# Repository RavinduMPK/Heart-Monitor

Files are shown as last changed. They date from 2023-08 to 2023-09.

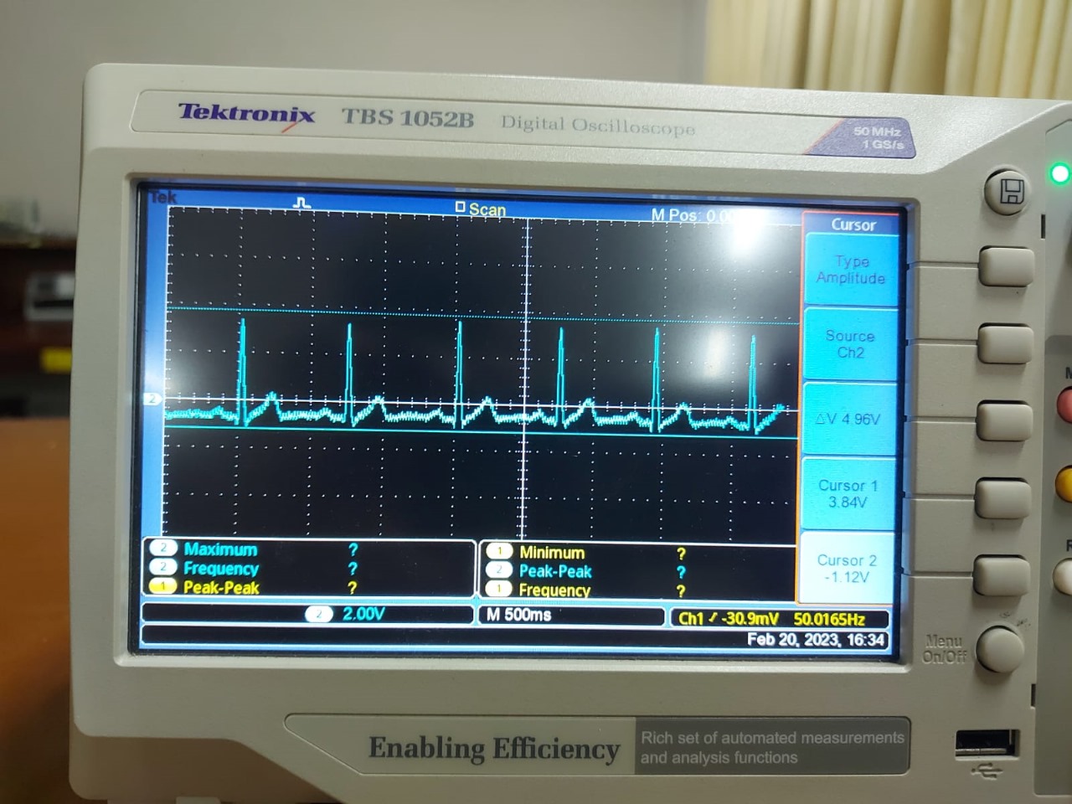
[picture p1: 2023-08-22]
images/Final result.jpg

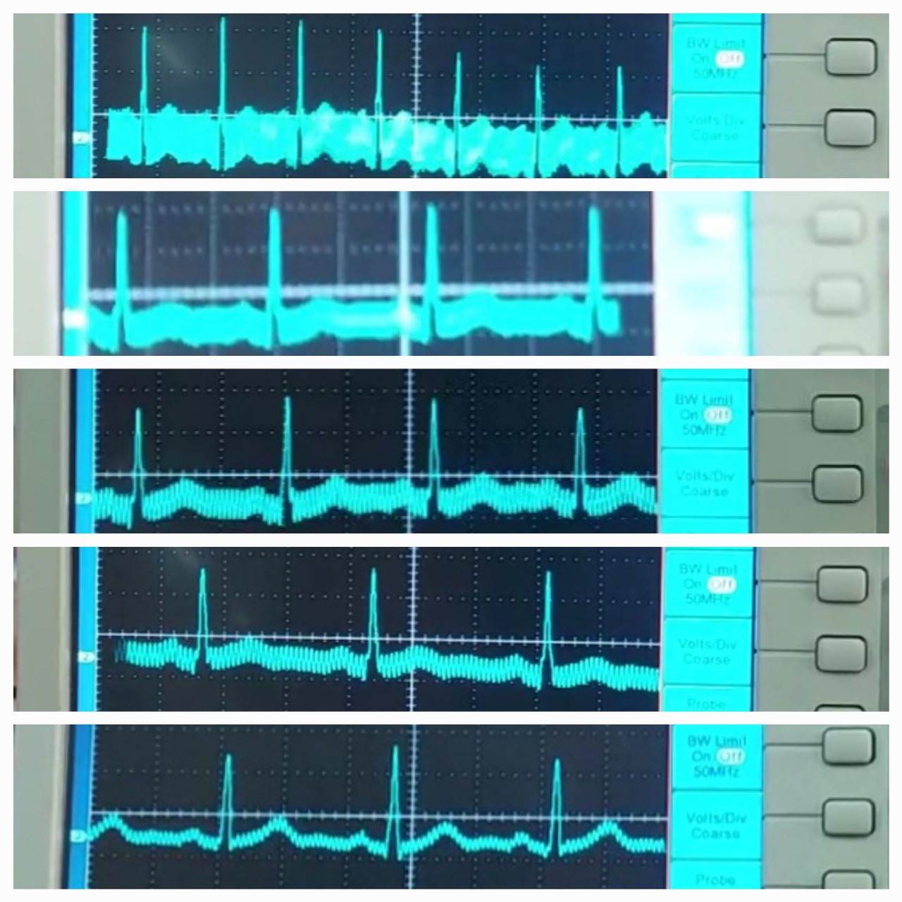
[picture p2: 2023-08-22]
images/Testing process.jpg

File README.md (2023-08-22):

# Heart-Monitor

During our third semester, we successfully designed an Analog Heart Rate Monitor, bringing together the realms of technology and healthcare. The project was also showcased for **EXMO'23** the flagship technological exhibition of the University of Moratuwa as a biomedical application of electronics and technology. 

Our team, consisting of Malith, Ravindu, Umesha, and Dilupa, were able to apply our knowledge of circuit design, PCB design, enclosure design, and software integration to create a device that progresses from sensing the heart rate to amplifying and filtering the signal, culminating in the display of the refined waveform. The main circuitry of the device was developed utilizing analog electronic components, as a learning opportunity of analog electronics as well. 

With the user-friendly interface, we were able to output a patient's ECG waveform in real-time and also tune the signal when necessary. Our project's output results were compared favorably and accurately to a commercial patient monitor. With the wealth of practical and hands-on experience we've acquired, we are poised to continue making impactful contributions to the advancement of healthcare through technology.

Final Product

What you can find here:

- Circuit Design
- Simulation Files
- Schematic Diagrams
- PCB Designs
- Enclosure Designs
- Arduino program file

## The Circuit Design
The ECG circuit mainly consists of 5 blocks. Those are,
- Right Leg Drive Circuit
- Instrumentation Amplifier
- Low Pass Filter
- High Pass Filter
- Notch Filter

When we discuss our design approach to the circuit;

### The Right Leg Drive Circuit
The right leg drive circuit (DRL) is used to reduce common-mode interference. Common-mode interference is unwanted electrical noise that is picked up by the ECG electrodes and amplified along with the ECG signal. This noise can obscure the ECG signal and make it difficult to interpret.

The DRL circuit works by injecting a known voltage into the right-leg electrode. This voltage is equal to the common-mode voltage that is being picked up by the other electrodes. The ECG amplifier then subtracts this known voltage from the signal from the other electrodes, effectively canceling out the common-mode noise.

The DRL circuit is typically used in conjunction with other methods of noise reduction, such as filtering and shielding. The choice of which methods to use depends on the specific application.

Leg Drive

### Instrumentation Amplifier
An instrumentation amplifier is a critical component in our ECG circuit design. Its primary purpose is to amplify sensitive electrical signals originating from the body while minimizing distortion. This is crucial for accurate ECG signal acquisition since the electrical potentials generated by the heart are extremely low in amplitude.

The instrumentation amplifier consists of multiple operational amplifiers arranged in a specific configuration to achieve high common-mode rejection ratio (CMRR), which helps in removing unwanted noise that is picked up by the electrodes. By effectively amplifying the difference between two input signals while rejecting common-mode signals, the instrumentation amplifier improves the signal-to-noise ratio of the ECG measurement.

In addition to amplifying the ECG signal, the instrumentation amplifier also provides a means to adjust the gain as needed. This enables customization of the signal's amplitude for optimal visualization on the display.

Instrumentation Amplifier

### Low Pass Filter
We implemented a 5th order Bessel-Thompson low pass filter in our circuit. This filter is designed to attenuate high-frequency noise and unwanted components beyond a certain cutoff frequency while preserving the integrity of the ECG signal. The Bessel filter is chosen for its minimal group delay, which helps maintain the shape and timing of the ECG waveform.

The Bessel-Thompson filter comprises a series of cascaded first-order and second-order active filter stages. These stages collectively contribute to the filter's response, ensuring that frequencies beyond the cutoff are effectively attenuated while minimizing distortion and phase shift. By carefully selecting the filter's components and structure, we ensure that the amplified ECG signal is clean and devoid of high-frequency noise.

Low Pass filter

### High Pass Filter
Our ECG circuit incorporates a 3rd order active inverting Butterworth high-pass filter. This filter serves multiple purposes, including removing the DC offset that may develop between the electrodes and further amplifying the signal.

The high-pass filter's design focuses on attenuating low-frequency components, which typically include DC offset and slow baseline drift. The filter's configuration involves a cascade of a second-order active non-inverting stage followed by a first-order active inverting stage. The combined effect of these stages results in eliminating DC offset while providing additional signal amplification.

A variable resistor is integrated into the high-pass filter, allowing us to adjust the gain of the first-order filter stage according to the requirements of the specific ECG measurement.

High pass filter

### Notch Filter
To eliminate the interference caused by the 50 Hz power line frequency, we integrated a Twin-T type notch filter into our ECG circuit.

The Twin-T notch filter is known for its ability to provide a deep notch at a specific frequency, making it effective at eliminating power line interference. In our case, the notch frequency is set to 50 Hz to target the power line frequency. The filter's quality is determined by the Q factor, which influences the sharpness of the roll-off at the notch frequency.

To accommodate variations in the interference and notch frequency, we included a variable resistor that allows us to adjust the Q factor and achieve optimal filtering. This ensures that the ECG waveform remains free from the influence of power line noise, contributing to accurate and reliable heart rate measurements.

With these components and configurations, our analog heart rate monitor circuit is capable of capturing, amplifying, and filtering the ECG signal to produce a clean and accurate representation of the heart's electrical activity. The combination of the right leg drive circuit, instrumentation amplifier, low pass filter, high pass filter, and notch filter results in a robust ECG measurement system suitable for biomedical applications.

Notch Filter

## Simulation 
We used LTspice software to simulate and verify our circuit.
Simulation

## The Enclosure Design
The enclosure was designed by Solidworks software. It contains a removable top lid, a removable front, and the main body. The removability was integrated to fix and replace components. Holes surrounding the box are integrated to ensure that the heat flow to the outside of the box due to the power components inside. A fan is also connected inside to help with this. The front contains the display and also the knobs for tuning the filters. The switch on top switches off the device, and can be used for temporary situations. And the switch at the back, switches off the transformer as well, saving
the power loss that happens at the transformer. The enclosure also contains holes containing the adapters to connect the power cable and also to
connect the 3.5mm jack.

Enclosure main
Enclosure full
Enclosure front

## PCB Design
The heart rate monitor's PCB design involved several key considerations that contributed to the final product's performance and reliability. One of the pivotal decisions was the configuration of a 4-layer PCB. This choice allowed us to take advantage of its multilayer structure for improved signal integrity, reduced interference, and effective heat dissipation.

The arrangement of the layer stack was meticulously planned to optimize the PCB's performance. By thoughtfully allocating power and ground planes and strategically positioning signal traces, we aimed to create a layout that minimized noise and interference while providing stable voltage references for our sensitive analog components.

In the process of routing traces, special attention was given to the layout's integrity. We took great care to minimize issues such as cross-talk, impedance mismatches, and electromagnetic interference.

PCB layers

The placement of components on the PCB played a vital role in achieving signal fidelity and effective thermal management. Components were arranged to minimize signal distortion and ensure efficient heat dissipation. By considering the interaction between components, we aimed to create a layout that enhanced the overall functionality and reliability of the heart rate monitor.

PCB

Upon finalizing the PCB design, we collaborated with JLC PCB, a reputable PCB manufacturer, for production. Their expertise and advanced manufacturing processes ensured the accurate reproduction of our design.

## Testing and Final Results
Throughout the development of our heart rate monitor project, rigorous testing played a pivotal role in ensuring the accuracy and reliability of our device. Initially, we implemented the circuit on breadboards, meticulously connecting components and validating the functionality of each stage. This iterative testing approach allowed us to address any issues early in the design process and refine our circuitry.

Bread board implementation

To observe the ECG waveform and monitor signal behavior, we utilized an oscilloscope. This powerful tool enabled us to visualize the signal characteristics, detect any anomalies, and fine-tune our circuit parameters for optimal performance.

Testing process

Recognizing the dynamic nature of power line interference, we introduced variable resistors into the notch filter circuit. This innovation provided us with the flexibility to adjust the notch filter frequency as needed. By adapting to variations in interference over time, we could consistently attain a clean and accurate ECG waveform.

After iterative adjustments and thorough testing, we achieved our goal: a heart rate monitor that delivered more accurate and reliable ECG waveforms. The collective efforts of our team, from circuit design and simulation to PCB layout and meticulous testing, culminated in a final product that accurately captures and displays the heart's electrical activity. This accomplishment underscored the success of our project and its potential to make meaningful contributions to healthcare through technology.

Final result

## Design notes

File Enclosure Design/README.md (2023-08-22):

##  Enclosure Design using Solidworks

The enclosure of our heart rate monitor project was meticulously crafted using Solidworks, a powerful 3D modeling software. This phase of the project was essential to provide a robust and functional housing for our circuitry and components.

In our enclosure design, we took a comprehensive approach to ensure that all components were accommodated optimally. Spaces were carefully planned and designed to house the three PCBs that constituted the heart rate monitor's intricate circuitry. By providing dedicated mounting areas for each PCB, we enhanced the structural integrity and organized layout of the device.

The transformer, a pivotal component in our power supply circuit, also found its place within the enclosure. We allocated a specific location for the transformer, ensuring it was securely mounted while considering ventilation for heat dissipation.

To address thermal management, a cooling fan was incorporated into the design. The enclosure was thoughtfully crafted to accommodate the cooling fan, ensuring proper airflow to prevent overheating and maintain consistent performance.

Display visibility and user interaction were prime considerations in our design. We created an optimized space to mount the display, ensuring it was easily viewable and integrated seamlessly with the enclosure. User-adjustable components, such as potentiometers for tuning filters, were also given careful attention to make sure they were comfortably accessible without compromising the overall aesthetics and functionality.

Furthermore, we meticulously designed holes for the input and output interfaces. This included crafting holes to mount the 3.5mm audio jack for signal input, as well as apertures for power input and cable connections. These precise apertures ensured seamless connectivity while maintaining the enclosure's clean and professional appearance.

The culmination of our enclosure design was achieved through local 3D printing. By translating our Solidworks design into a physical enclosure, we created a protective casing that encapsulated our entire heart rate monitor project. This enclosure not only served as a shield against external elements but also contributed to the aesthetic appeal of the final device.

In essence, our Solidworks-based enclosure design was a testament to our commitment to detail and functionality. By thoughtfully considering the arrangement of components, thermal management, user interaction, and structural integrity, we created a housing that complemented the sophistication of our internal circuitry. The successful local 3D printing of the enclosure brought our design to life, underscoring the importance of an integrated and holistic approach to device development.

Enclosure

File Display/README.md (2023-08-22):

## Display
The final stage of our heart rate monitor project involved translating the analog ECG signal into a digital format and presenting it on a visual display. To accomplish this, we employed an ATmega328p microcontroller. This microcontroller served as the bridge between the analog world of our ECG signal and the digital realm of data processing.

Given the ATmega328p's input range limitation of 0V to 5V, a re-scaling of our ECG output was necessary. To achieve this, we designed a dedicated circuit and PCB that accurately converted the amplified ECG signal to fit within the ATmega328p's operating range.
Offset Circuit

Once the hardware was in place, we proceeded to code the ATmega328p microcontroller. The code was responsible for interfacing with the analog-to-digital converter (ADC) of the microcontroller, reading the re-scaled ECG signal, and then driving the visual display. Through careful coding and calibration, we ensured that the digital representation of the ECG waveform accurately mirrored the heart's electrical activity.
Display Circuit

In essence, this final phase of the project brought together hardware design, analog-to-digital conversion, microcontroller programming, and display output. The result was a user-friendly display that showcased the heart rate monitor's output in a clear and informative manner, making it accessible and valuable for medical professionals and patients alike.

Display PCB

Display 3D

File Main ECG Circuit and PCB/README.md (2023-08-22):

Here I have added Altium Design Files (Schematics, PCB files) and also zipped Altium Project.

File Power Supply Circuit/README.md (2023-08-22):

## Power Supply Circuit

The power supply circuit in our heart rate monitor project was a critical component that provided the necessary electrical energy for the device to function reliably. Here are the key aspects of our power supply design:

To power our device, we utilized a domestic AC power supply rated at 230V/50Hz. Given the different voltage and nature of the AC supply compared to our device's requirements, we needed to go through several steps of transformation and regulation.

We began by stepping down the voltage from 230V AC to a safer and usable level. To achieve this, we incorporated a 230V to 15V step-down transformer. This initial transformation ensured that the voltage was within an appropriate range for further processing.

The next step was to obtain a stable DC output for the heart rate monitor's internal circuitry. For this purpose, we designed a power supply PCB that included a rectifier bridge and voltage regulators. The rectifier bridge efficiently converted the AC voltage to a pulsating DC voltage, and then we employed L7812 and L7912 voltage regulators to generate +12V and -12V DC outputs, respectively.

As our circuit incorporated operational amplifiers (opamps), it was necessary to have both positive and negative supply voltages. Therefore, the power supply design incorporated both +12V and -12V lines to accommodate the requirements of the opamps.

To ensure smooth and stable DC outputs, we integrated smoothing circuits that reduced the residual ripple in the rectified DC signal. This smoothed DC output was vital to provide a clean and reliable power source for the heart rate monitor's sensitive analog circuitry.

Power Supply Circuit

Power Supply PCB

Power Supply PCB 3D

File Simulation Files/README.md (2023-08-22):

## Circuit Simulation

Simulation played a crucial role in ensuring the accuracy and reliability of our heart rate monitor project. To achieve this, we turned to LTspice, a powerful simulation tool, to thoroughly design and validate our circuitry before physical implementation.

We embarked on our simulation process by breaking down our circuit into its sub-circuits, mirroring the actual components and connections in LTspice's virtual environment. This allowed us to accurately model the behavior of each individual component, ensuring that our design was free from inherent errors and inconsistencies.

By simulating our sub-circuits within LTspice, we gained valuable insights into how they interacted and responded to varying inputs. This simulation stage allowed us to fine-tune parameters and values to optimize the performance of each circuit block.

One of the key advantages of LTspice was its ability to provide a comprehensive analysis of the circuit's behavior. We could observe waveforms, plot graphs, and analyze parameters such as gain, frequency response, and signal distortion. This level of detail enabled us to detect potential issues and make informed design decisions early in the process.

Furthermore, LTspice aided us in pinpointing potential areas of concern, such as noise susceptibility and unwanted distortion. This proactive approach empowered us to address such issues in the simulation stage, leading to a more robust and reliable final circuit design.

The LTspice simulations also helped us validate our circuit's functionality under various scenarios, such as different heart rate patterns and noise interference. This extensive testing gave us confidence that our heart rate monitor would perform accurately in real-world situations.

Simulation

*_And also we used ECG waveform sample signal to verify our circuit_*

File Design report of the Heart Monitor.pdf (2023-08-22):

## Department of Electronic & Telecommunication Engineering Faculty of Engineering University of Moratuwa

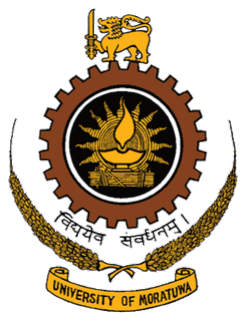
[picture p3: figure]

# Heart Monitor

by CardioTech

Bandara D.M.D.V. | Jayalath K.A.D.M.P.
Undergraduate (Biomedical engineering) | Undergraduate (Biomedical engineering)
Department Electronic and Telecommunications | Department Electronic and Telecommunications
Faculty of Engineering | Faculty of Engineering
University of Moratuwa | University of Moratuwa
Pushpakumara H.M.R.M. | Tilakarathna U.A.
Undergraduate (Biomedical engineering) | Undergraduate (Biomedical engineering)
Department Electronic and Telecommunications | Department Electronic and Telecommunications
Faculty of Engineering | Faculty of Engineering
University of Moratuwa | University of Moratuwa

February 28, 2023(ongoing)

## Contents

1 Introduction | 1
2 Design Specifications | 1
3 Functionality Description | 2
4 Design Parameters | 4
5 PCB Design and Soldering | 5
6 Enclosure Design | 5
7 Simulation and Testing | 5
8 Results | 5
9 Task allocation | 6
References | 6
Appendix I: Schematics, PCB’s, Enclosure | 7
Appendix II: Simulation and Testing | 9
Appendix III: Display Code | 12

I

## Abstract

Our project is a heart monitor that outputs and displays the ECG waveform. The challenge is to amplify the small ECG voltage signal of range 0.1mV - 10 mV which gets largely affected by noise. To achieve this a leg drive circuit, an instrumentation amplifier, a high pass filter, a low pass filter and a notch filter were used. The bandwidth considered was 160 Hz. To achieve this, only analog electronic components were used. Digital electronic components were used only in the digital circuit. Simulation testing, breadboard testing, and PCB testing was done to test the functionality of the circuit. A 3D enclosure was designed and built to suit the device.

## 1 Introduction

An electrocardiogram (ECG) is a simple test that can be used to check the heart’s rhythm and electrical activity through sensors attached to the skin, which detects electrical signals generated by the heart each time it beats. The voltage between right arm and left arm is amplified while having a feedback mechanism through the right leg. These voltages of right arm, left arm and right leg are taken from ECG leads (Figure 1). The amplitude of the voltage signal has a range of 0.1 mV-10 mV; while its frequency falls into 0.01 Hz-250 Hz. Amplifying this signal becomes a challenge due to the small amplitude of the ECG raw signals and their ease of corruption due to noise and disturbances such as power line interference, electrostatic potentials, RFI, electrode contact noise, stray capacitance, nearby electronic devices and also bio signal artifacts introduced into an ECG by subject movement, respiration and muscle tension. In certain situations, noise can override the ECG waves and make the amplified signal useless.

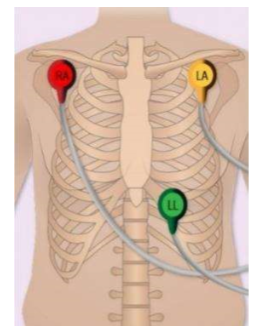
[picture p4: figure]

Figure 1: 3 Lead ECG placement (https://www.conectmed.com/3-lead-ecg-and-placement.html)

Our project is an ECG device, which amplifies and displays the above mentioned voltage waveform. We only used analog electronic equipment except for the display unit. In this report we have explained how we achieved this. For the ECG waveform generation, we have used below mentioned circuits to achieve the final output.

1. Right Leg Drive Circuit.
2. Instrumentation Amplifier.
3. 3

rd Order active Butterworth high pass filter.

4. 5

th Order active Bessel Thompson low pass filter.

5. Notch Filter.

And two separate circuits, with a PCB for each was used for power supply and display screen. In each filter circuit, we have used variable resistors to adjust the gains, adjust and reduce noise and disturbances depending on the location, and unstable power supplies. The total approximate gain achieved through adjustments in the circuit is 1000.

## 2 Design Specifications

### 2.1 Filter Specifications

The ECG falls onto the frequency range of 0.01 Hz
- 250 Hz. The American Heart Association (AHA) recommends a minimum bandwidth of 150 Hz for children between the ages of 12 to 16 years; and a minimum bandwidth of 125 Hz for adults. To filter out the signal to this range from the noise and other disturbances, three filters are used. The high pass filter cut off frequency we used was 0.05 Hz and the low pass filter cut off frequency was 160 Hz. Conductive gel between leads and the body also supports minimizing noise.
The other main issue is the power line interference. To avoid this a notch filter of 50 Hz is used in the circuit.
The overall gain of the ECG waveform should be above 1000 as per the standards. Therefore, the filter gain is made such that this goal is achieved. Variable resistors are used in the filters to increase and decrease the gain as necessary.

### 2.1.1 Op amp Selection

To reduce the high noise added to the small raw ECG signal, an op amp with high CMRR is used in the instrumentation amplifier. Generally, the

CMRR should at least be above 100dB, therefore, we used the LM4562 opamp which has a typical CMRR of 120dB.

### 2.2 Sampling Rate

The sampling ADC sampling rate chosen was 15,000 samples per second. This is the maximum sampling rate of the ADC of the Atmega328pU chip.

## 3 Functionality Description

### 3.1 ECG Circuit

Block Diagram

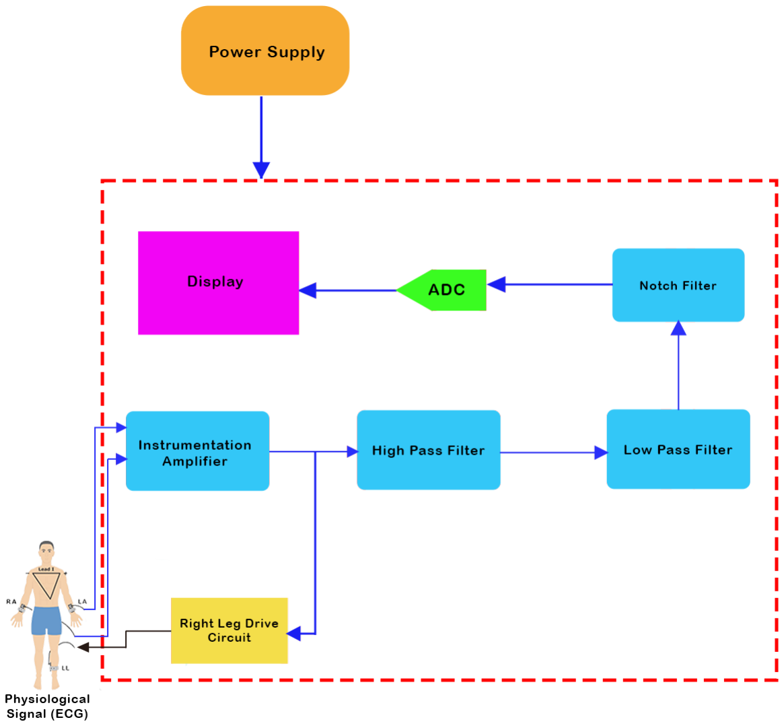
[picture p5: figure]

### 3.1.1 Right Leg Drive Circuit

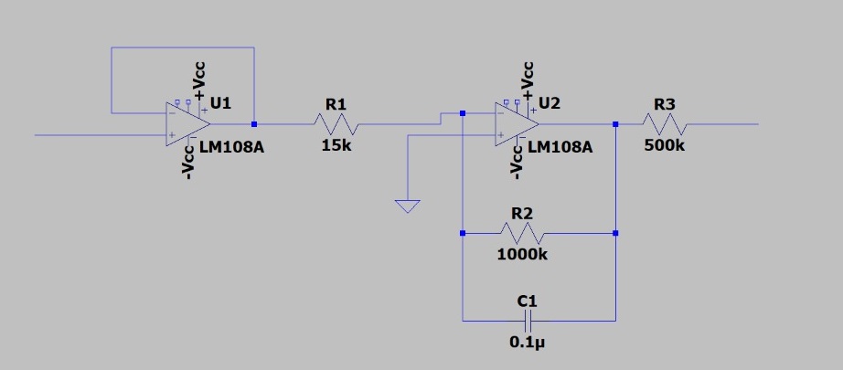
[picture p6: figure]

Figure 2: Right Leg Drive

A right leg drive circuit is used to cancel the common-mode signal between the left and right arm electrodes by inverting, amplifying, and then feeding the signal back to the body through the right leg electrode.The high value resistors used in this circuit also ensures that the patient connected does not get in contact with a bigger current.

### 3.1.2 Instrumentation amplifier

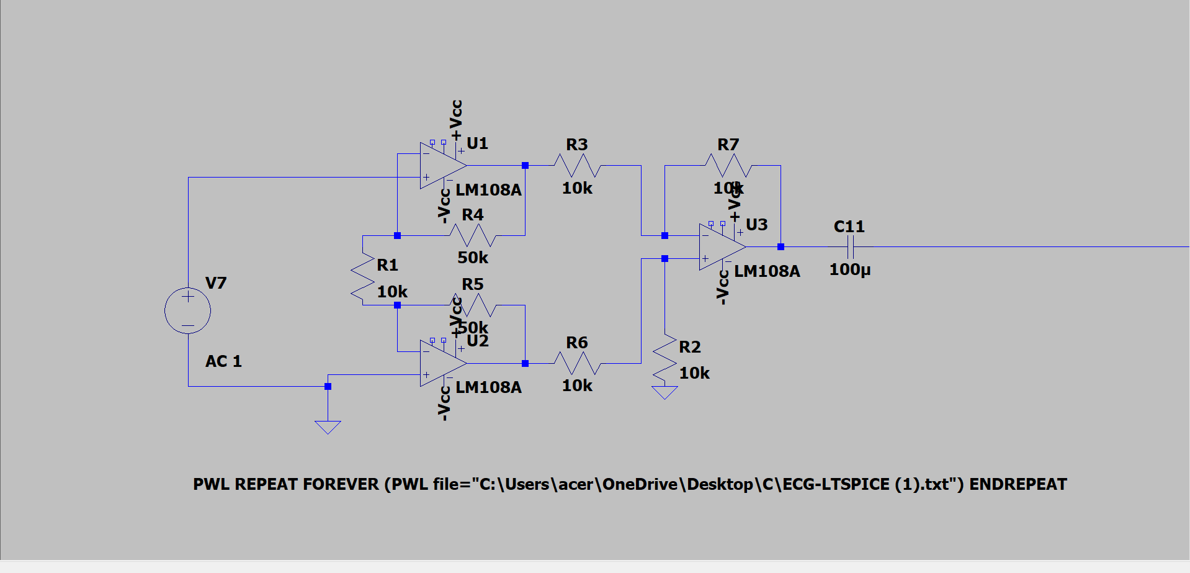
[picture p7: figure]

Figure 3: Instrumentation amplifier

This circuit is used to amplify the signal, while removing the common noise of the voltages from ECG leads. The three inputs are converted to the single output through this circuit. The gain of our circuit in the instrumentation amplifier is kept in the range 20-50. We have used a variable resistor at R1(Refer figure 1) to adjust the gain as necessary.

### 3.1.3 High Pass Filter

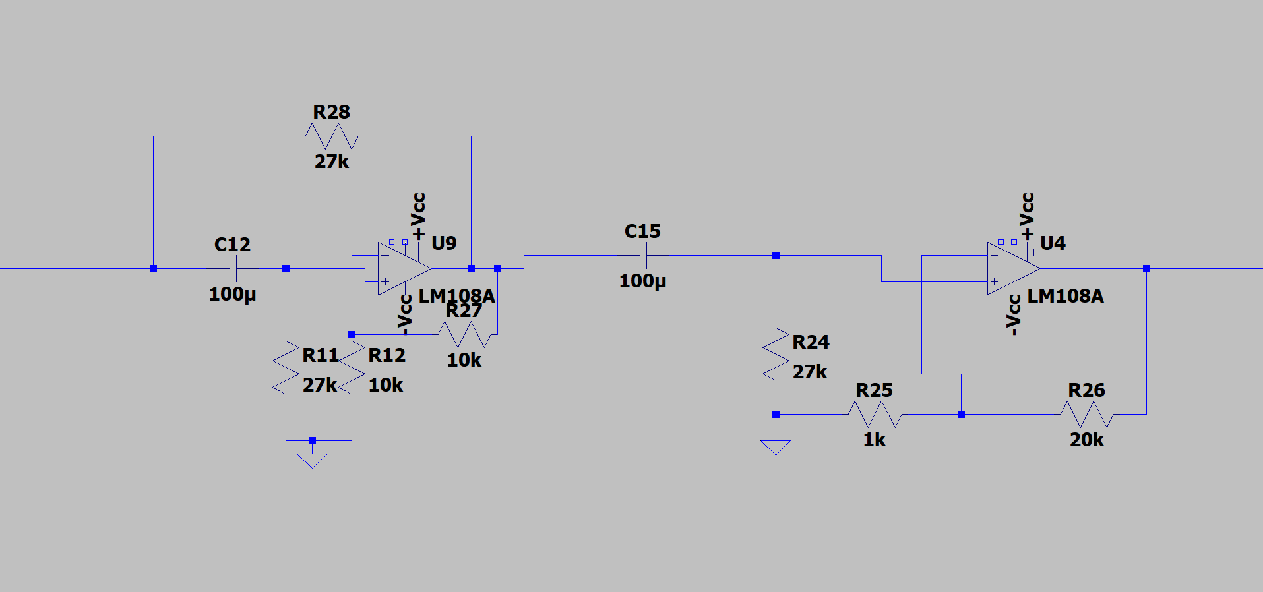
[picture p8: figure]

Figure 4: High Pass Filter

Here we have used 3rd order active inverting Butterworth filter. This consists of a cascaded second order active non inverting filter and a first order active inverting filter. This circuit eliminates the DC offset developed between the electrodes, and also amplifies the signal further. The gain of the second order filter is 2, and the minimum gain of the first order filter connected is 20, making the minimum overall gain of the high pass filter 20 × 2 = 40. The gain of the first order filter can be further increased when required through the variable resistor connected.

### 3.1.4 Low Pass Filter

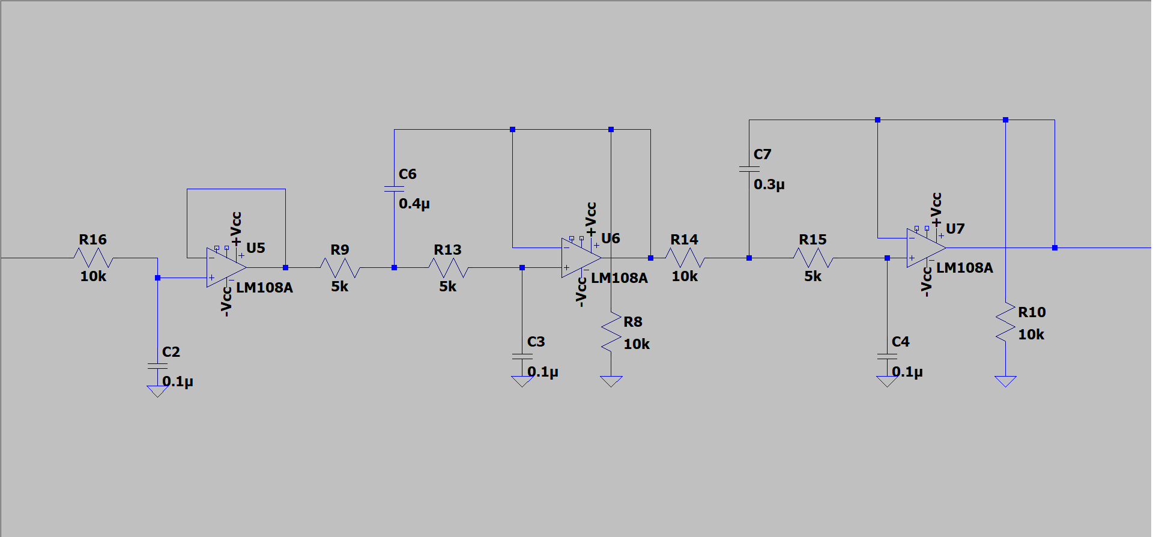
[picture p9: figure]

Figure 5: Low Pass Filter

Here, we used a 5th order Bessel Thompson non inverting filter. Compared to the Butterworth filter, since the group delay and the signal distortion caused is absent, we chose this filter. This consists of a series cascaded first order active filter, and two second order active filters. The gains of each are unity, causing the overall gain of the low pass filter a unity. No adjustments to the gain are made, and therefore, we didn’t use a variable resistor here.

### 3.1.5 Notch Filter

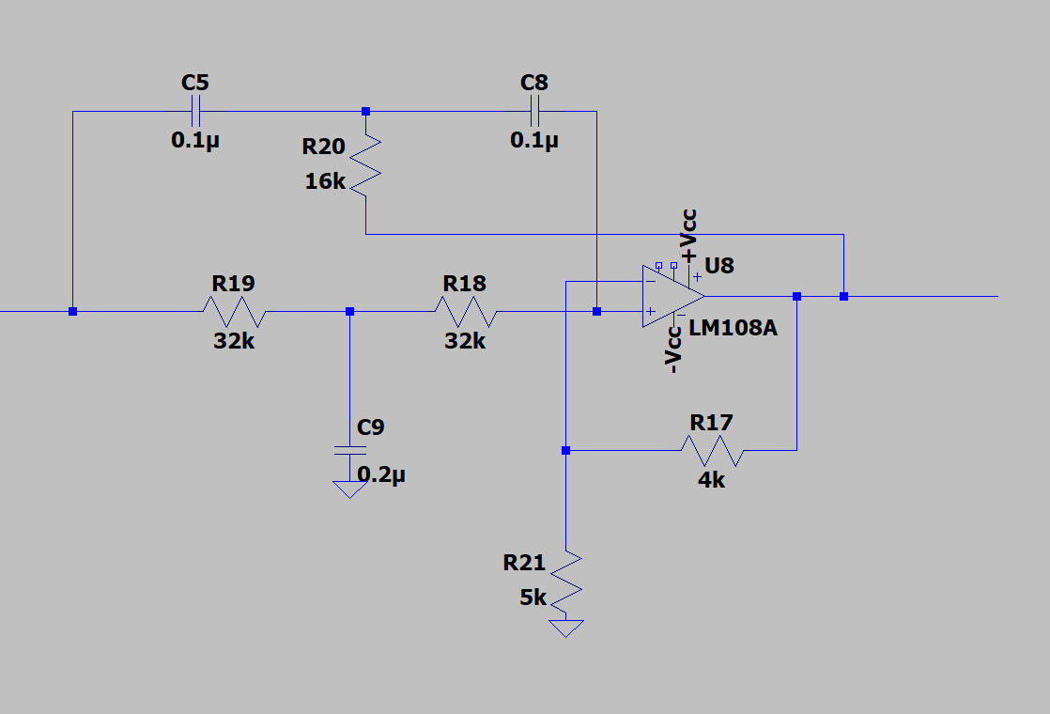
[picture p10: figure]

Figure 6: Notch Filter

Here we have used a Twin-T type notch filter. This is used to eliminate the power line interference. Therefore the notch filter frequency is 50 Hz. This requires a small transition bandwidth or high Q factor to achieve the steeper roll-off. A Twin-T notch filter is one of the few RC networks capable of providing an infinite deep notch at a particular frequency. Therefore, we used this particular filter. The Q factor, or else known as the quality factor determines the quality of the filter. To adjust this as necessary, a variable resistor is used as. The notch frequency depends on three resistor values. To adjust that when necessary, three tuners are used.

### 3.2 Display Circuit

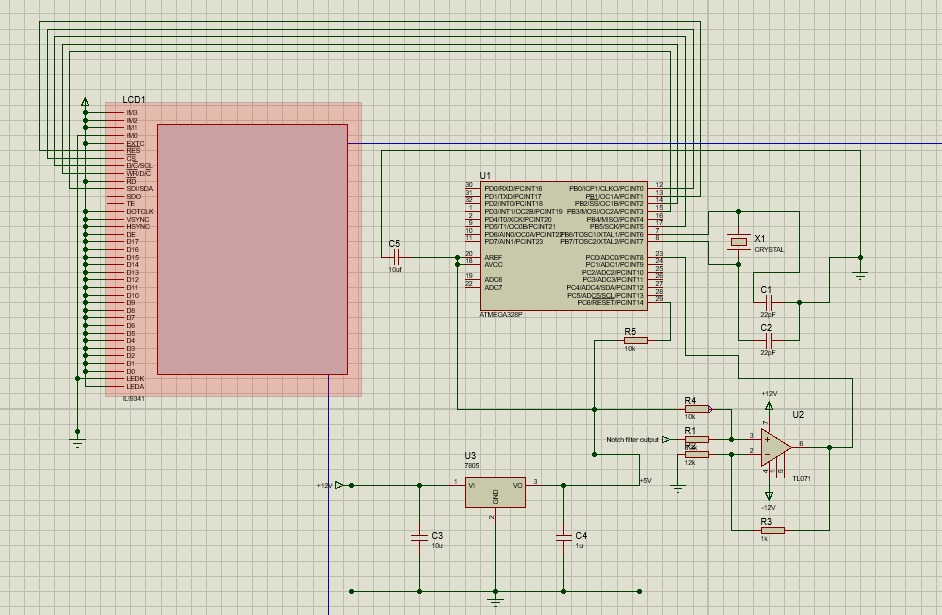
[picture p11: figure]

Figure 7: Display

The output from the notch filter is directed through an Atmega328pU chip to a display to plot the ECG waveform and display it in real time. In the circuit, we bring down the 12V supply to 5V (Using a L7805 regulator) to power the Atmega chip and the display. Another 2-pin outlet is also designed in here to power the fan. The code is provided in the appendix (cite)

### 3.3 Power Supply Circuit

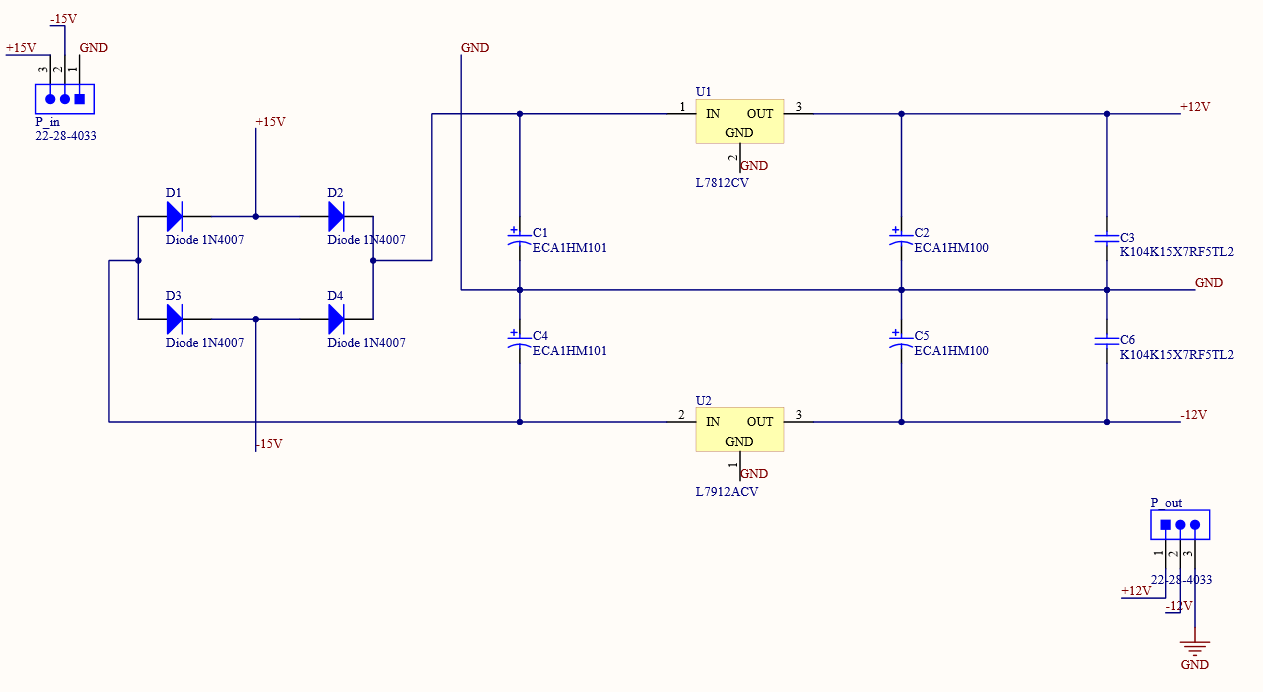
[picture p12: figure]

Figure 8: Power Supply

As we need a power supply of +12V, 0V and -12V s for the functionality of the op amps, we built a separate circuit to provide the required voltages. Here, the AC voltage of household of 230 V, is sent through a center tap transformer that outputs two AC signals of 30 V peak to peak value. These two signals are sent through rectifier diode circuit to make the signals DC, and then through 7812 to regulate the DC voltage to +12 V and then through 7912 to regulate -12 V.

## 4 Design Parameters

- Gain resistor value of instrumentation amplifier:

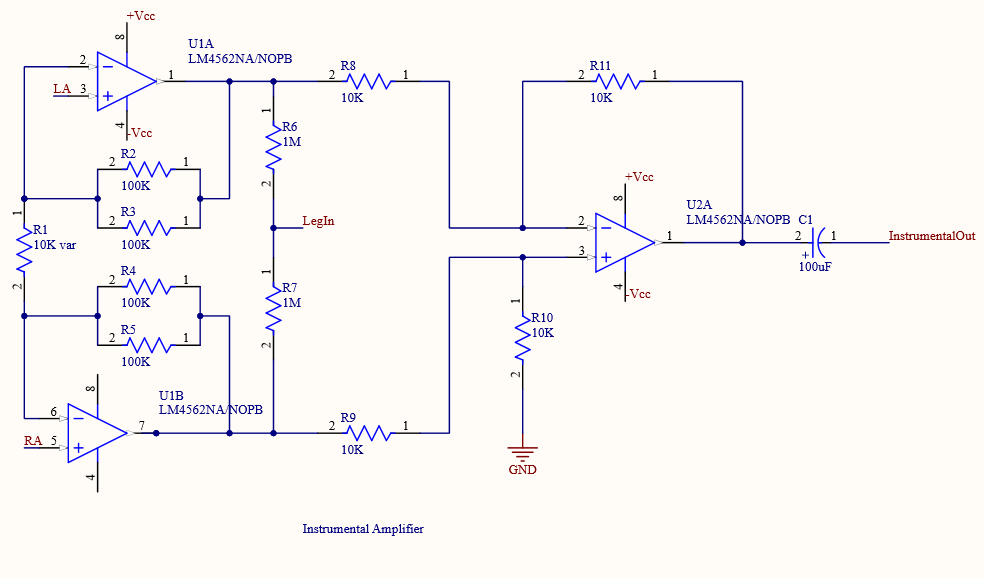
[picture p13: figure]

Figure 9: Instrumental amplifier

Gain =

R10
R9

2R + R1
R1

(

10kΩ
10kΩ

(1 + 2 × 50kΩ
R1

Here, R = R4//R5 = R2//R3

M inimum Gain = 1 +

2 × 50 kΩ
10kΩ
= 11

We can increase this by changing the value of the R1 variable resistor, and get the gain to the required range of 20 - 50.

- The cut off frequency of the high pass filter:

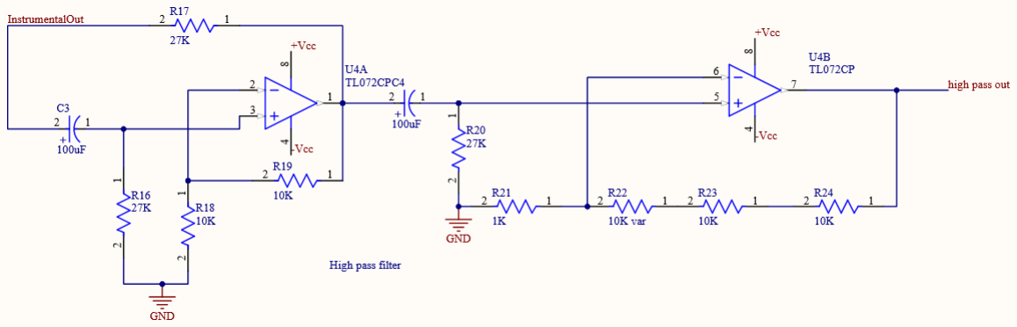
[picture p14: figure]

Figure 10: High pass filter

fn =

1
2πRC =

1
2π × R16 × C3

=

1
2π × 27kΩ × 100µF
= 0.0589Hz

The resistor and capacitor values were taken such that the required cut off frequency can be achieved through the available components in the market.

- Gain of the high pass filter:

consider, Gain 2 order = Gain of the second order active filter

Gain 1 order = Gain of the first order active filter

Gain = Gain 2 order × Gain 1 order

Gain 2 order = 1 +

R19
R18

= 1 +

10kΩ
10kΩ

= 2

Gain 1 order = 1 +

R22 + R23 + R24
R18

This can be changed by varying the value of the 10kΩ variable resistor at R21.

M aximum gain = 1 +

R22 + R23 + R24
R21
= 31
- Cut off frequency of the low pass filter:

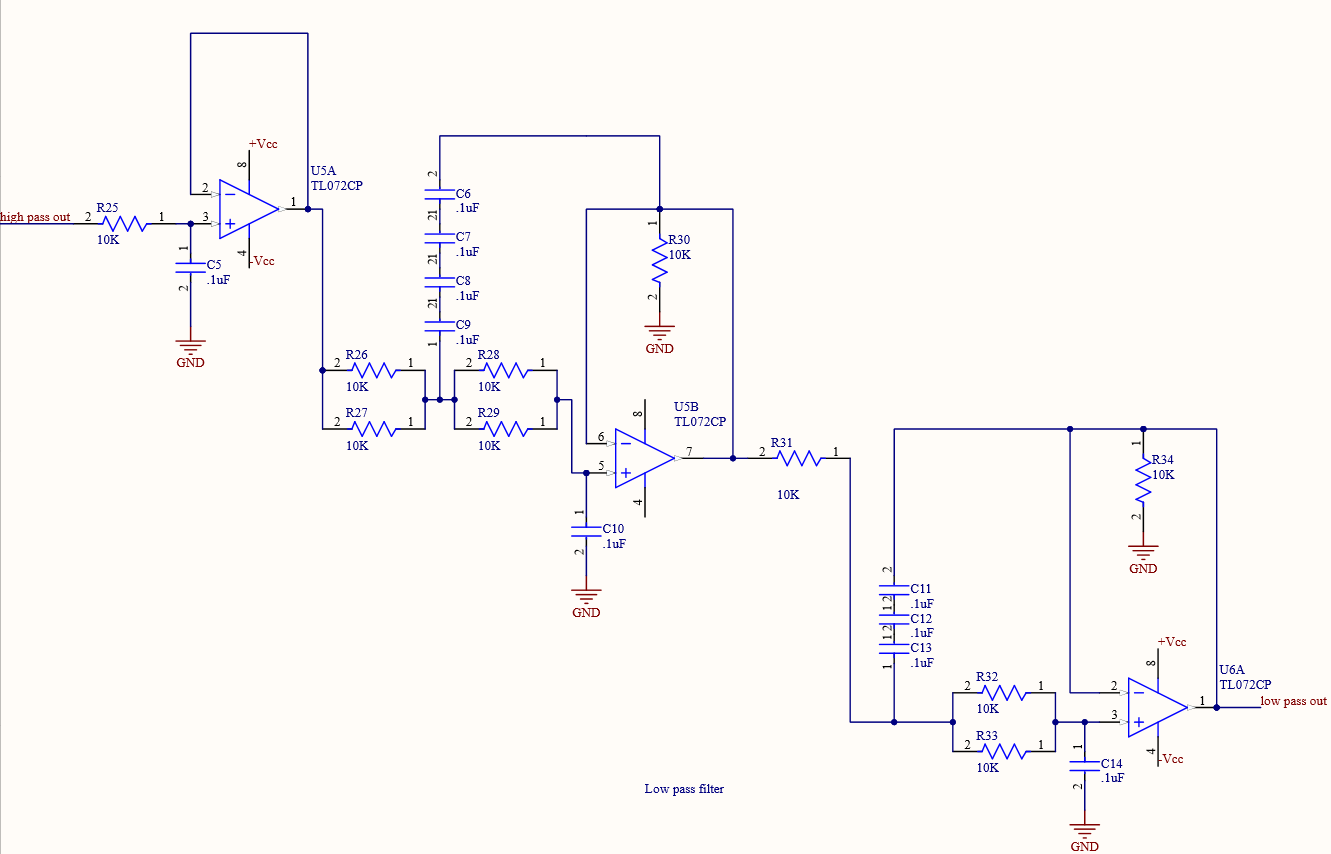
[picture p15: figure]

Figure 11: low pass filter

fn =

1
2πRC

=

1
2π × R25 × C5

=

1
2π × 10kΩ × 0.1µF
= 159.154Hz

- Cut off frequency of the notch filter

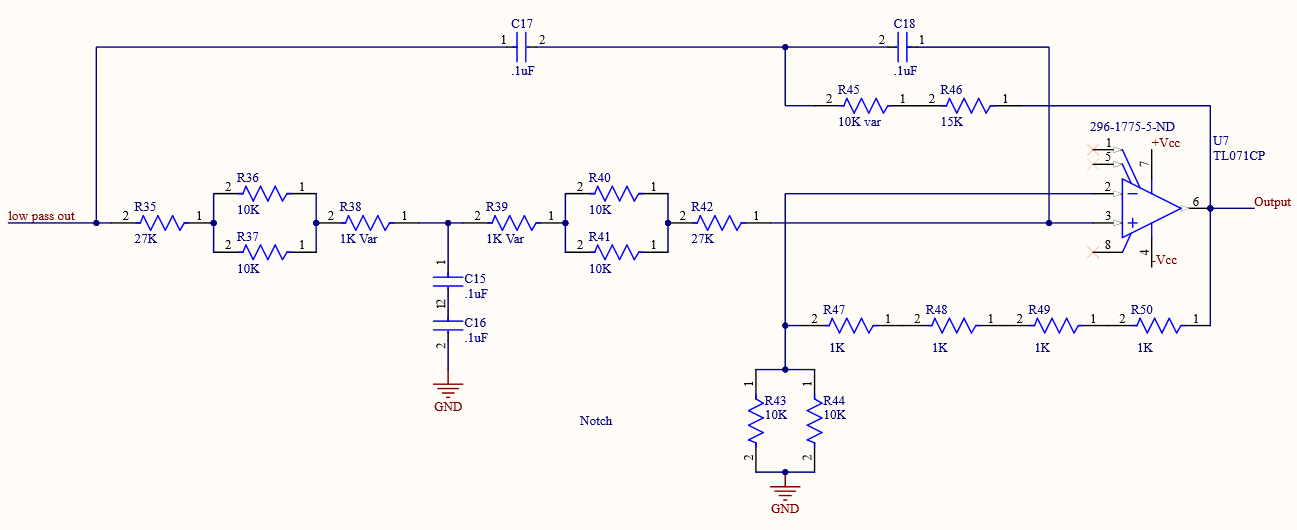
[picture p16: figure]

Figure 12: low pass filter

fn =

1
2πRC
Here, R = 27kΩ+10kΩ//10kΩ+1kΩ(variable)

fn =

1
2π × 32kΩ × 0.1µF

= 49.73Hz

The capacitor values and resistor values were chosen as available market values. Three variable resistors were used at R38, R39 and R45 to maintain the Twin T configuration, by mitigating the effect of tolerances.

The other variable resistor at R48, was used to adjust the gain.

- Gain of the notch filter:

Gain = 1 +

R47 + R48 + R49 + R50
R43//R44

= 1 +

4kΩ
5kΩ
= 1.8

## 5 PCB Design and Soldering

Three PCBs, namely a power circuit, a heart monitor circuit, and a display circuit, were designed using Altium Designer for printing. The ECG PCB is of 4 layers (Figure 13). The 3rd layer carries +12V and -12V power supply routings and the Top and bottom layers are used for routing. Power supply PCB(Figure 14a) was routed in a single layer but printed in 2 layer(Remaining layer grounded) to reduce the capacitance building up. Ground pours are poured to both single layers and the remaining layer to reduce further noise. Except for the display circuit (Figure 14b), the rest has been imported, and the display PCB is etched. All of them are soldered with relevant components; all the ICs are coupled with IC bases for easy replacement;

and interconnections with accessories outside the circuit have been done with pin headers and jumpers.

## 6 Enclosure Design

The enclosure was designed by solidworks (Figure 15).
It contains a removable top lid, and a removable front. The removability helps to fix and replace components. The holes surrounding the box ensures that the heat flow to the outside of the box, and thus the components do not get damaged. A fan is also connected inside to help this.
The front contains the display and also the knobs for tuning the filters. The switch on top switches off the device, and can be used for temporary situations. And the switch at the back, switches off the transformer as well, saving the power loss that happens at the transformer. The enclosure also contains holes containing the adapters to connect the power cable and also to connect the 3.5mm jack.

## 7 Simulation and Testing

We first simulated our entire circuit using LTSpice and the display using Proteus(as shown in Figure
7) Then it’s implemented on a breadboard with minor adjustments to obtain a signal with the least amount of noise possible. From the changes in osciloscope display, we can see the overall improvement from the testing. (Figure 17 & 18)

## 8 Results

Final product is shown below.

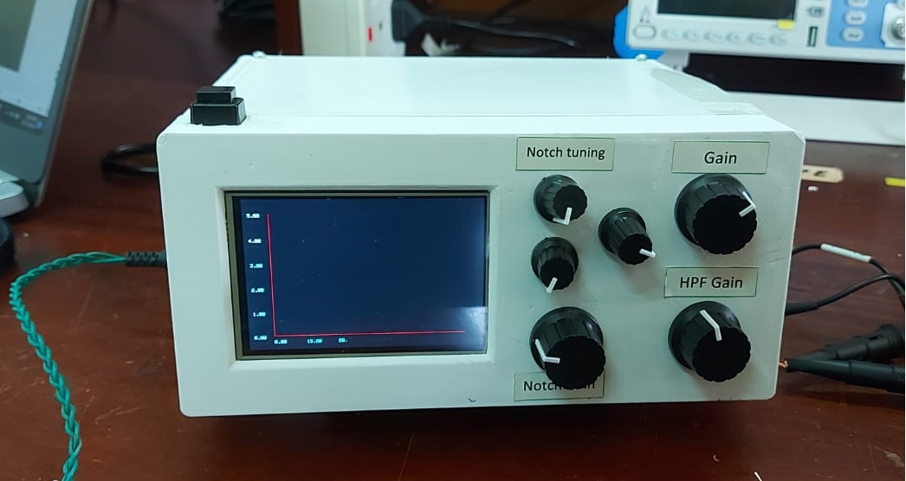
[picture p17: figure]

Though we faced some issues with display, the final result from the osciloscope is as shown in figure 19.

## 9 Task allocation

Index No. | Contribution
200061N 200247P 200488E 200664P | circuit and PCB designing Circuit designing, Display and coding Circuit and PCB designing Circuit and solidwork(enclosure) designing

## References

I Du WY, Jose W. Design of an ECG sensor circuitry for cardiovascular disease diagnosis. Int J Biosen Bioelectron. 2017;2(4):120–125. DOI: 10.15406/ijbsbe.2017.02.00032 (https://doi.org/10.15406/ijbsbe.2017.02.00032)

II Article : | Stack | exchanege/choosing-the-
right-op-amp-for-ecg-application (https://electronics.stackexchange.com/questions/571823/choosing-the-right-op-amp-for-ecg-application)

III Article: Robu.in/Dual Power Supply (https://robu.in/what-is-dual-power-supply-circuit-construction-and-working/)

IV Display Code Reference: github.com/KrisKasprzak (https://github.com/KrisKasprzak/Graphing)

## Appendix I: PCB’s and Enclosure design

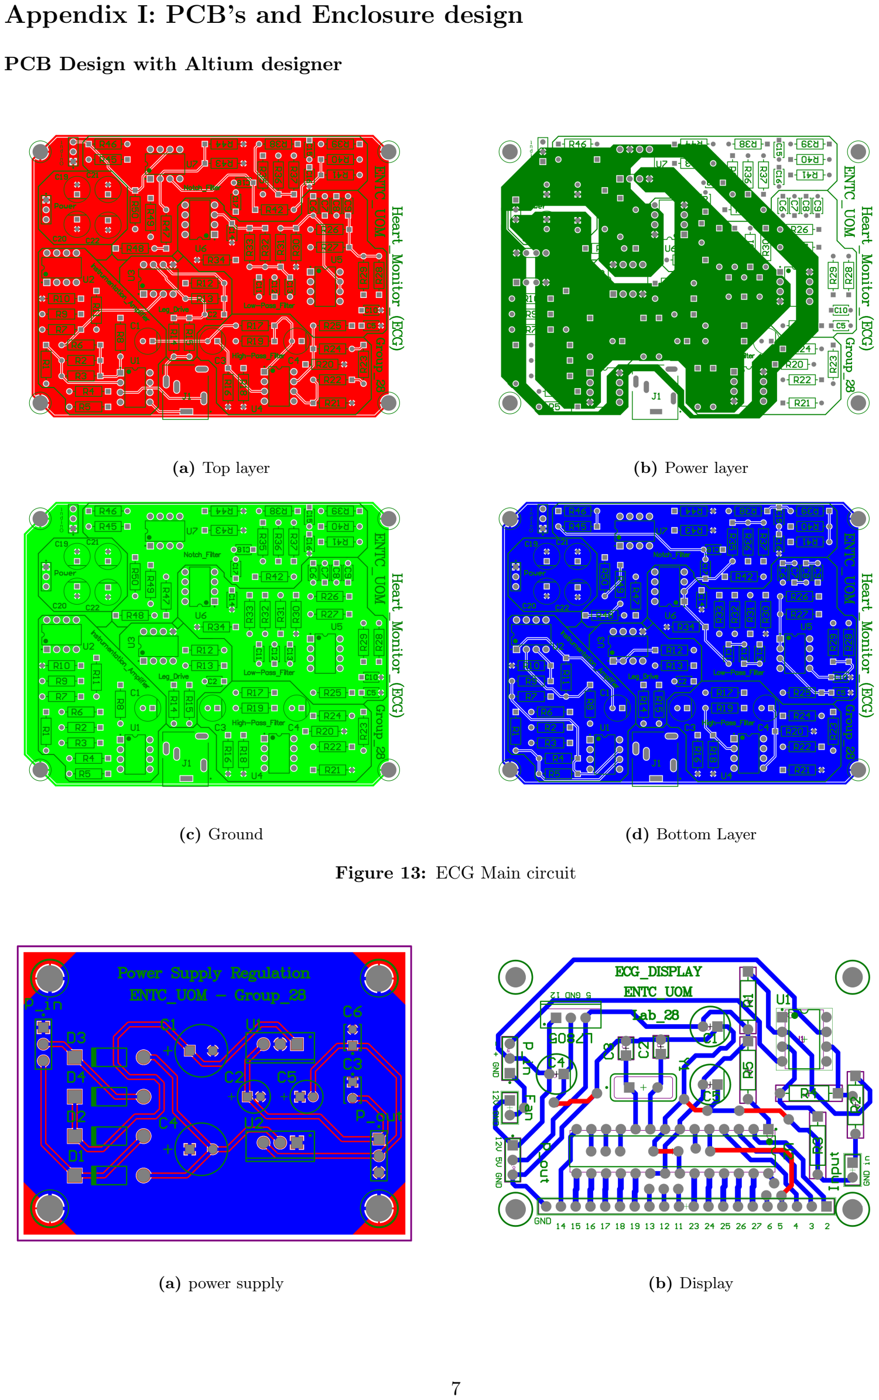
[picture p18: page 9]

PCB Design with Altium designer

(a) Top layer | (b) Power layer
(c) Ground | (d) Bottom Layer

Figure 13: ECG Main circuit

(a) power supply | (b) Display

Enclosure with solidworks

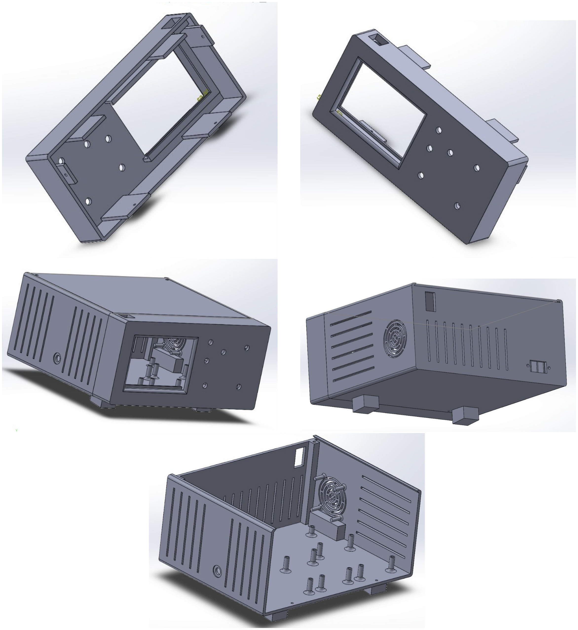
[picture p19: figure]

Figure 15: enclosure

## Appendix II: Simulation and Testing

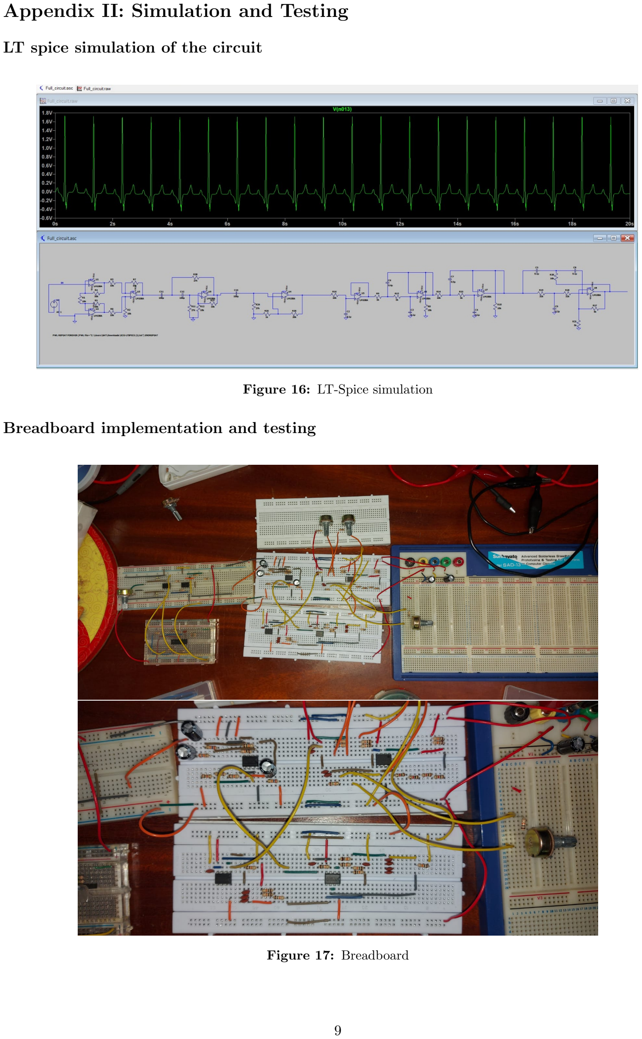
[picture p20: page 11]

LT spice simulation of the circuit

Figure 16: LT-Spice simulation

Breadboard implementation and testing

Figure 17: Breadboard

Results from Breadboard implementation and tuning

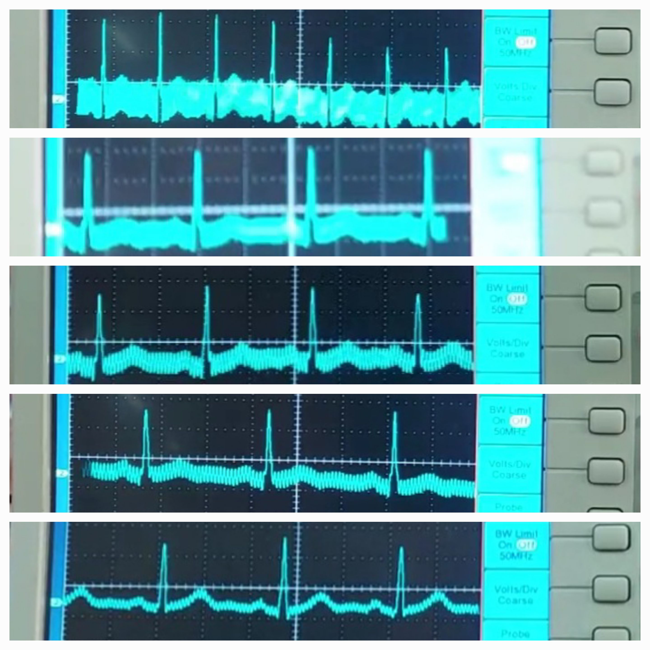
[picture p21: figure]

Figure 18: Osciloscope readings from breadboard tuning

Final Result After finalizing the Product.

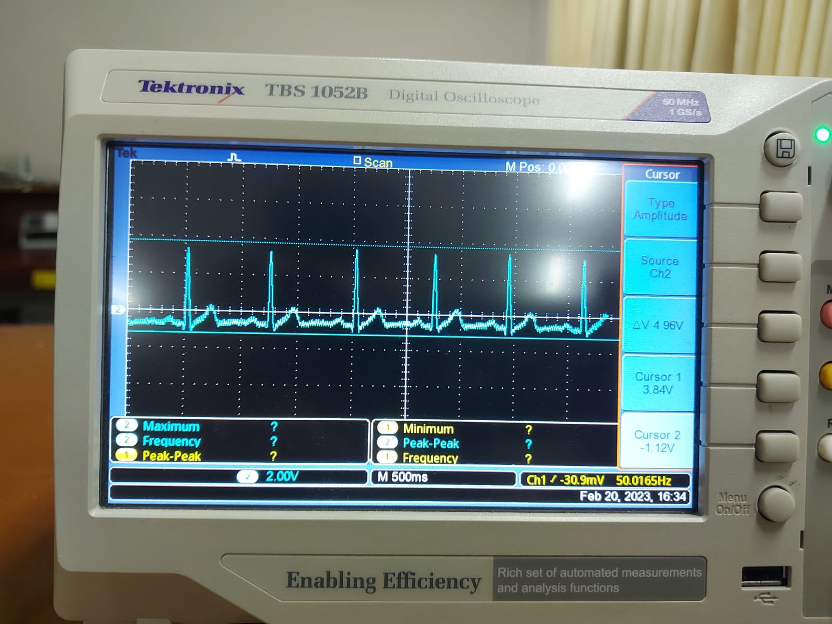
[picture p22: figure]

Figure 19: Final Output

## Appendix III: Display Code

#i n cl u d e <Adafruit GFX . h>

#i n cl u d e <Adafruit TFTLCD . h>

#d e f i n e LCD CS A3

#d e f i n e LCD CD A2

#d e f i n e LCD WR A1

#d e f i n e LCD RD A0

#d e f i n e LCD RESET A4

#d e f i n e ADJ PIN A5

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

d ouble vo ;
d ouble ox , oy ;

Adafruit TFTLCD t f t (LCD CS, LCD CD, LCD WR, LCD RD, LCD RESET ) ;

v oid Graph ( Adafruit TFTLCD &d , d ouble x , d ouble y , d ouble gx , d ouble gy , d ouble w, d ouble h , d ouble xlo , d ouble xhi , d ouble xinc , d ouble ylo ,
d ouble yhi , d ouble yinc , S t ri n g t i t l e , S t ri n g xl a b el , S t ri n g yl a b el ,
un si gned i n t g c ol o r , un si gned i n t a c ol o r , un si gned i n t p c ol o r ,
\ un si gned i n t t c ol o r , un si gned i n t b c ol o r , b o ole an &redraw ) {

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

i f ( redraw == t r u e ) {

redraw = f a l s e ;
ox = ( x − xl o ) ∗ ( w) / ( xhi − xl o ) + gx ;
oy = ( y − yl o ) ∗ ( gy − h − gy ) / ( yhi − yl o ) + gy ; // draw y s c a l e
f o r ( i = yl o ; i <= yhi ; i += yi n c ) {
// compute the t r a n s f o rm
temp = ( i − yl o ) ∗ ( gy − h − gy ) / ( yhi − yl o ) + gy ;

i f ( i == 0 ) {
d . drawLine ( gx , temp , gx + w, temp , a c o l o r ) ;
}

e l s e {
d . drawLine ( gx , temp , gx + w, temp , g c o l o r ) ; }

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

// compute the t r a n s f o rm

temp = ( i − xl o ) ∗ ( w) / ( xhi − xl o ) + gx ; i f ( i == 0 ) {
d . drawLine ( temp , gy , temp , gy − h , a c o l o r ) ; }
e l s e {
d . drawLine ( temp , gy , temp , gy − h , g c o l o r ) ; }

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

}

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

d . drawLine ( ox , oy + 1 , x , y + 1 , p c ol o r ) ; d . drawLine ( ox , oy − 1 , x , y − 1 , p c ol o r ) ; ox = x ;
oy = y ;

}

/∗
End o f g r aphin g f u n c t i o i n
∗/

v oid se tup ( ) {
S e r i a l . b e gi n ( 9 6 0 0 ) ;
t f t . b e gi n ( 0 x9341 ) ;
t f t . f i l l S c r e e n (BLACK) ;
t f t . s e t R o t a ti o n ( 1 ) ;
pinMode (ADJ PIN , INPUT ) ;

f o r ( i n t x = 0 ; x < 6 0; x += 1 ) {
vo = analogRead (ADJ PIN ) / 2 0 4 . 6 ;
Graph ( t f t , x , vo , 5 0 , 2 9 0 , 3 9 0 , 2 6 0 , 0 , 6 0 , 1 0 , 0 , 5 , 1 , ”ECG MONITOR” , ” Time [ s ] ” , ” Heart r a t e ” , DKBLUE, RED, GREEN, WHITE, BLACK, di s pl a y 1 ) ;

d el a y ( 1 0 0 ) ;
}

d el a y ( 1 0 0 0 ) ;
t f t . f i l l S c r e e n (BLACK) ;

f o r ( i n t x = 0 ; x < 6 0; x += 1 ) {
vo = analogRead (ADJ PIN ) / 2 0 4 . 6 ;
Graph ( t f t , x , vo , 5 0 , 2 9 0 , 3 9 0 , 2 6 0 , 0 , 6 0 , 1 0 , 0 , 5 , 1 , ”ECG MONITOR” , ” Time [ s ] ” , ” Heart r a t e ” , DKBLUE, RED, GREEN, WHITE, BLACK, di s pl a y 2 ) ;

d el a y ( 1 0 0 ) ;
}

d el a y ( 1 0 0 0 ) ;
t f t . f i l l S c r e e n (BLACK) ; f o r ( i n t x = 0 ; x < 6 0; x += 1 ) {
vo = analogRead (ADJ PIN ) / 2 0 4 . 6 ;
Graph ( t f t , x , vo , 5 0 , 2 9 0 , 3 9 0 , 2 6 0 , 0 , 6 0 , 1 0 , 0 , 5 , 1 , ”ECG MONITOR” , ” Time [ s ] ” , ” Heart r a t e ” , DKBLUE, RED, GREEN, WHITE, BLACK, di s pl a y 3 ) ;

d el a y ( 1 0 0 ) ;
}

d el a y ( 1 0 0 0 ) ;
t f t . f i l l S c r e e n (BLACK) ;

f o r ( i n t x = 0 ; x < 6 0; x += 1 ) {
vo = analogRead (ADJ PIN ) / 2 0 4 . 6 ;
Graph ( t f t , x , vo , 5 0 , 2 9 0 , 3 9 0 , 2 6 0 , 0 , 6 0 , 1 0 , 0 , 5 , 1 , ”ECG MONITOR” , ” Time [ s ] ” , ” Heart r a t e ” , DKBLUE, RED, GREEN, WHITE, BLACK, di s pl a y 4 ) ;

d el a y ( 1 0 0 ) ;

}

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

f o r ( i n t x = 0 ; x < 6 0; x += 1 ) {
vo = analogRead (ADJ PIN ) / 2 0 4 . 6 ;
Graph ( t f t , x , vo , 5 0 , 2 9 0 , 3 9 0 , 2 6 0 , 0 , 6 0 , 1 0 , 0 , 5 , 1 , ”ECG MONITOR” , ” Time [ s ] ” , ” Heart r a t e ” , DKBLUE, RED, GREEN, WHITE, BLACK, di s pl a y 5 ) ;

d el a y ( 1 0 0 ) ;

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

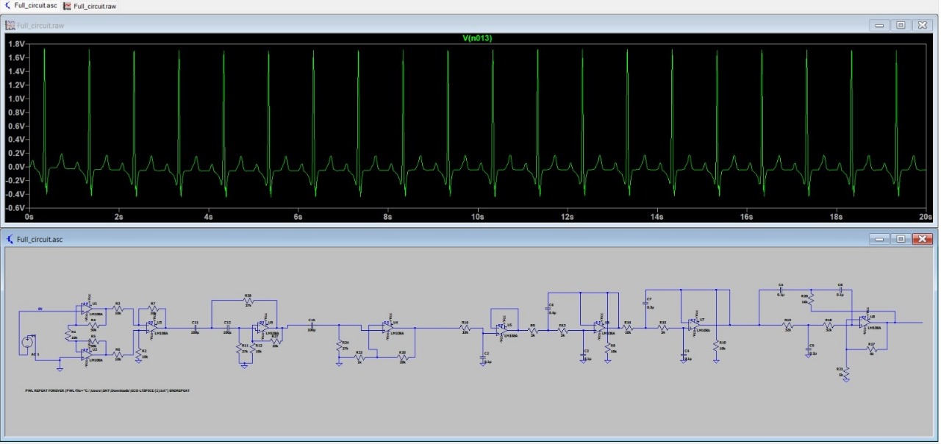
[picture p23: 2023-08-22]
images/Simulation.jpg

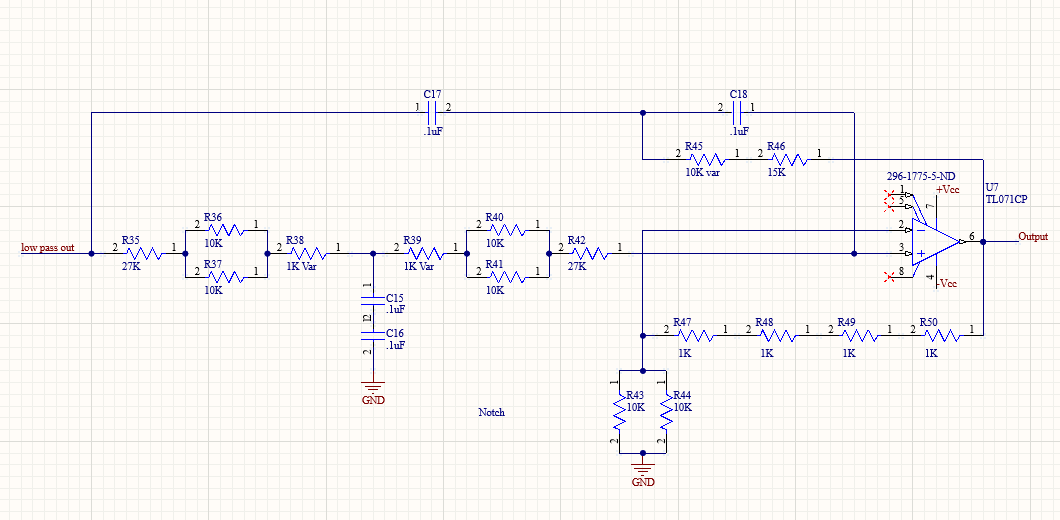
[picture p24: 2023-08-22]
images/Notch Filter.png

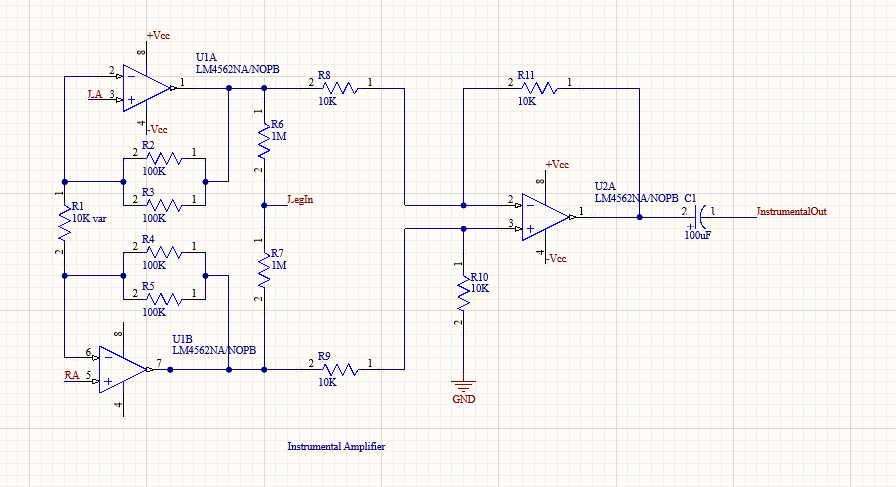
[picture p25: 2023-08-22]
images/Instrumentation Amplifier.png

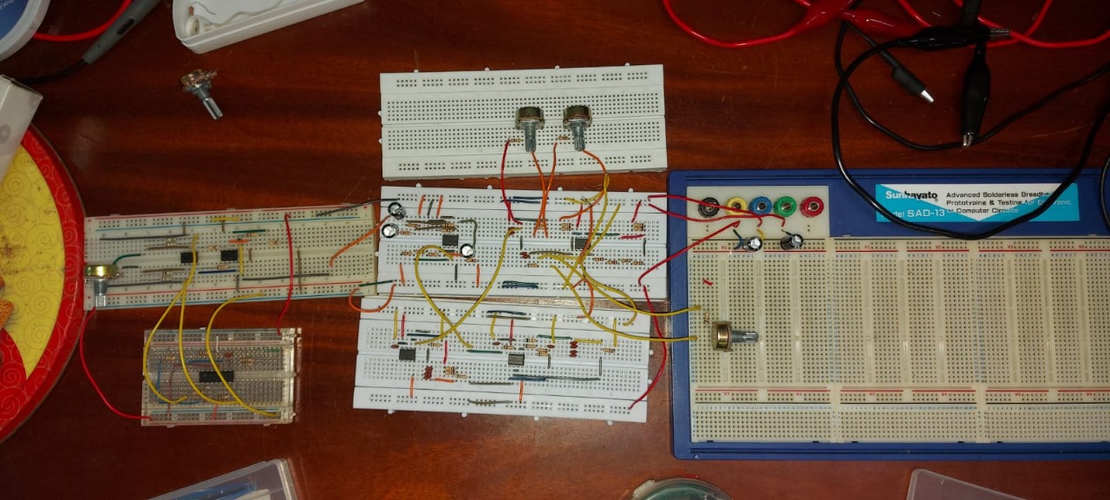
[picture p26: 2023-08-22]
images/Bread board implementation.jpg

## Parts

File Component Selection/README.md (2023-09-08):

## Component Selection

The process of selecting components for our heart rate monitor project was a critical phase in ensuring the performance, accuracy, and reliability of our device. Among the most pivotal selections were the operational amplifiers (opamps), which are at the heart of our analog circuitry.

A meticulous approach was taken to select opamps for the various circuit blocks. For our instrumentation amplifier—a key element in our circuit—it was imperative to choose opamps with a high Common-Mode Rejection Ratio (CMRR) to effectively suppress common-mode noise. Our selection criteria focused on opamps with a CMRR exceeding 120dB, ensuring that unwanted interference would be significantly attenuated.

In the design of active filters—another crucial component of our circuit—we carefully considered the opamp's slew rate. Slew rate is a key parameter that dictates how quickly an opamp can respond to rapid changes in input signals. Given that our filters play a vital role in shaping and processing the ECG waveform, we opted for opamps with sufficient slew rate to accurately handle the signal dynamics.

For the **_instrumentation amplifier_**, we chose the **_LM4562_** opamp, renowned for its high CMRR and low noise characteristics. This opamp met the stringent requirements of our instrumentation amplifier block, enabling us to amplify the ECG signal while effectively canceling common-mode noise.

In designing our filters, we selected the **_TL072_** and **_TL071_** opamps. These opamps offered an optimal balance between slew rate, noise performance, and compatibility with our filter design requirements. Their ability to handle the intricacies of active filter circuitry contributed to the accurate shaping and conditioning of the ECG waveform.

The component selection process extended beyond opamps to encompass various other components, each chosen with precision to fulfill its specific role in the circuit. By carefully evaluating datasheets, considering performance specifications, and aligning selections with our design goals, we curated a set of components that collectively contributed to the overall success of our heart rate monitor project.

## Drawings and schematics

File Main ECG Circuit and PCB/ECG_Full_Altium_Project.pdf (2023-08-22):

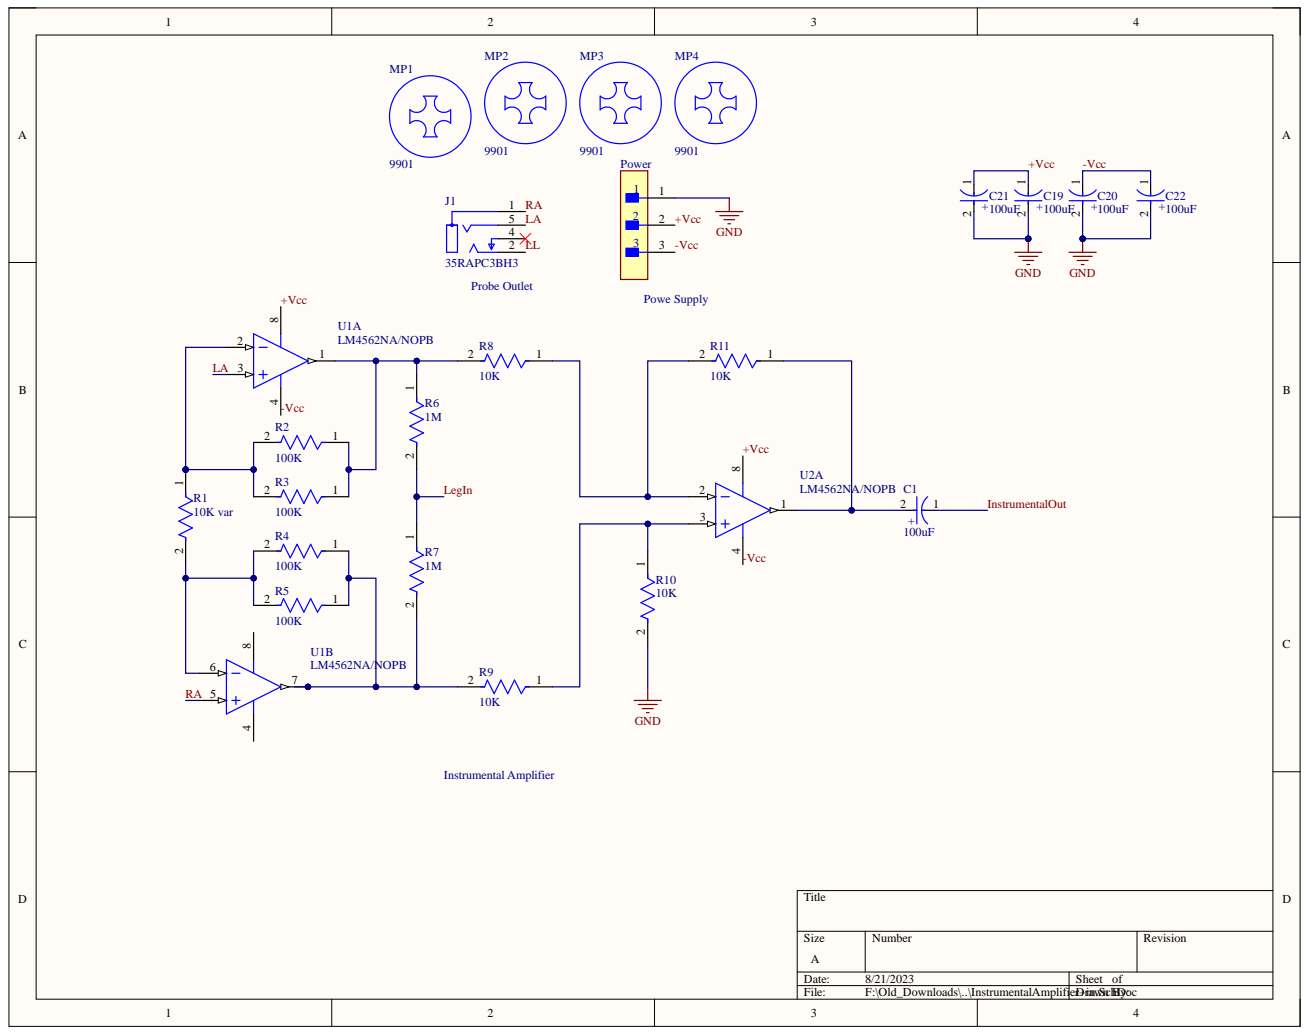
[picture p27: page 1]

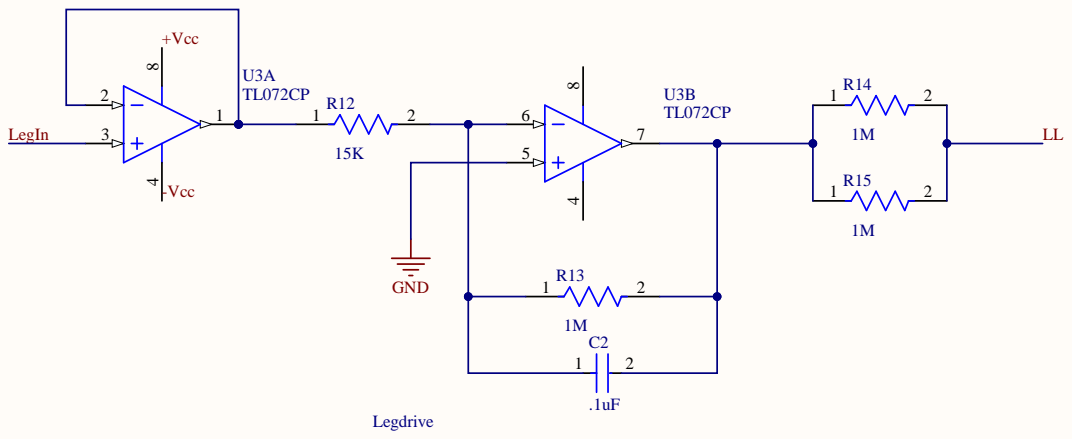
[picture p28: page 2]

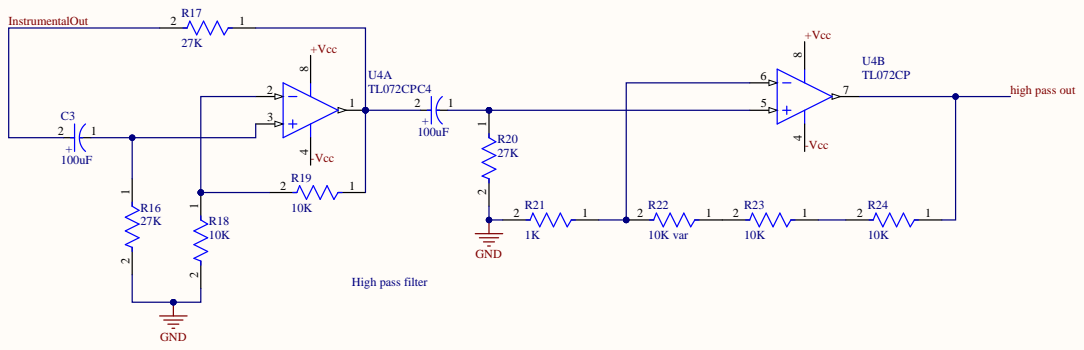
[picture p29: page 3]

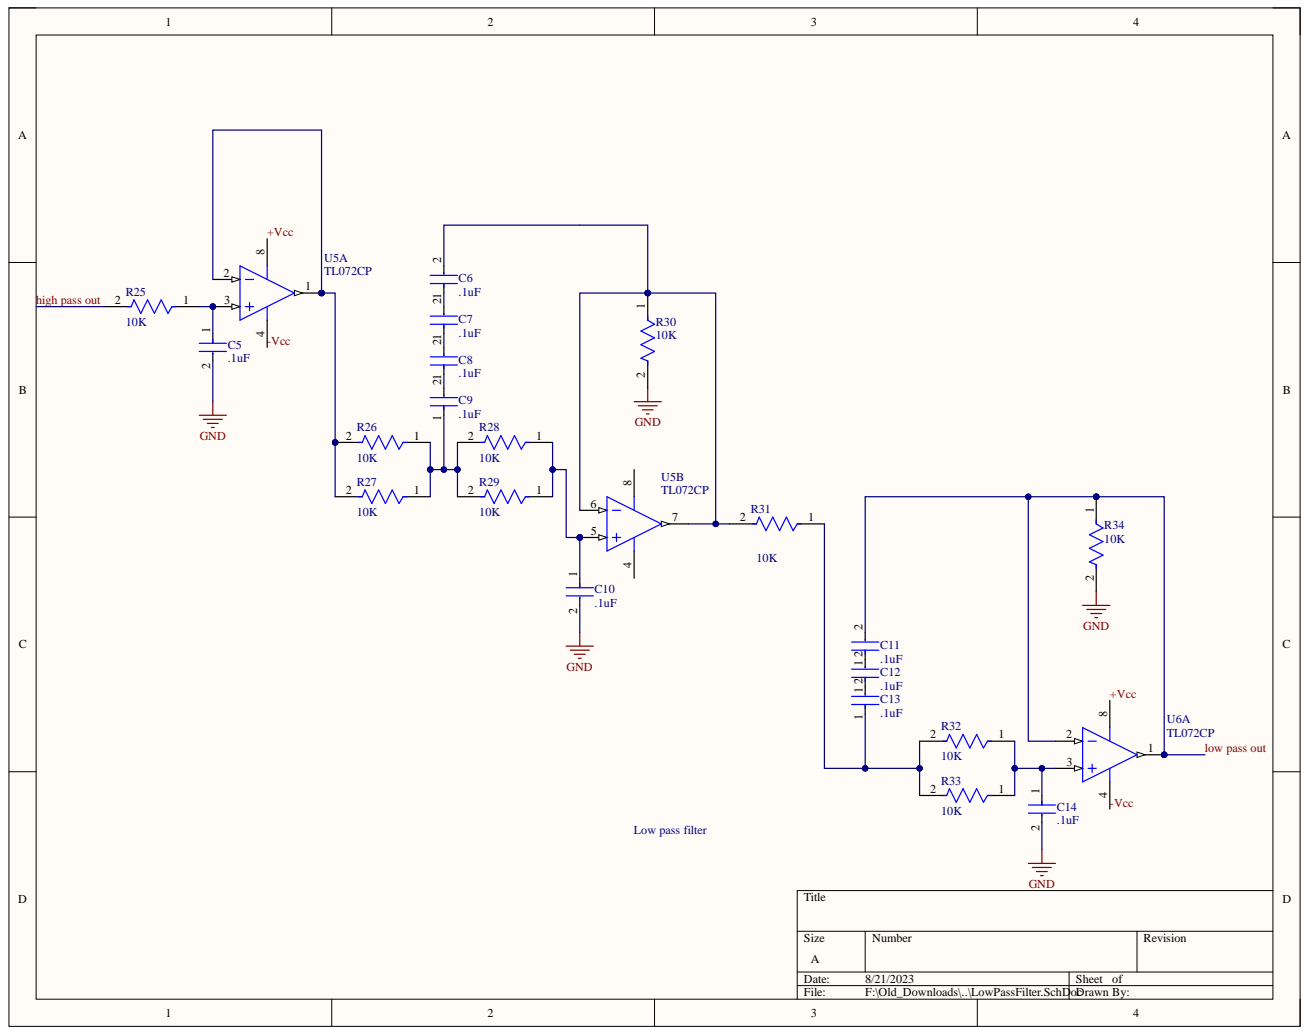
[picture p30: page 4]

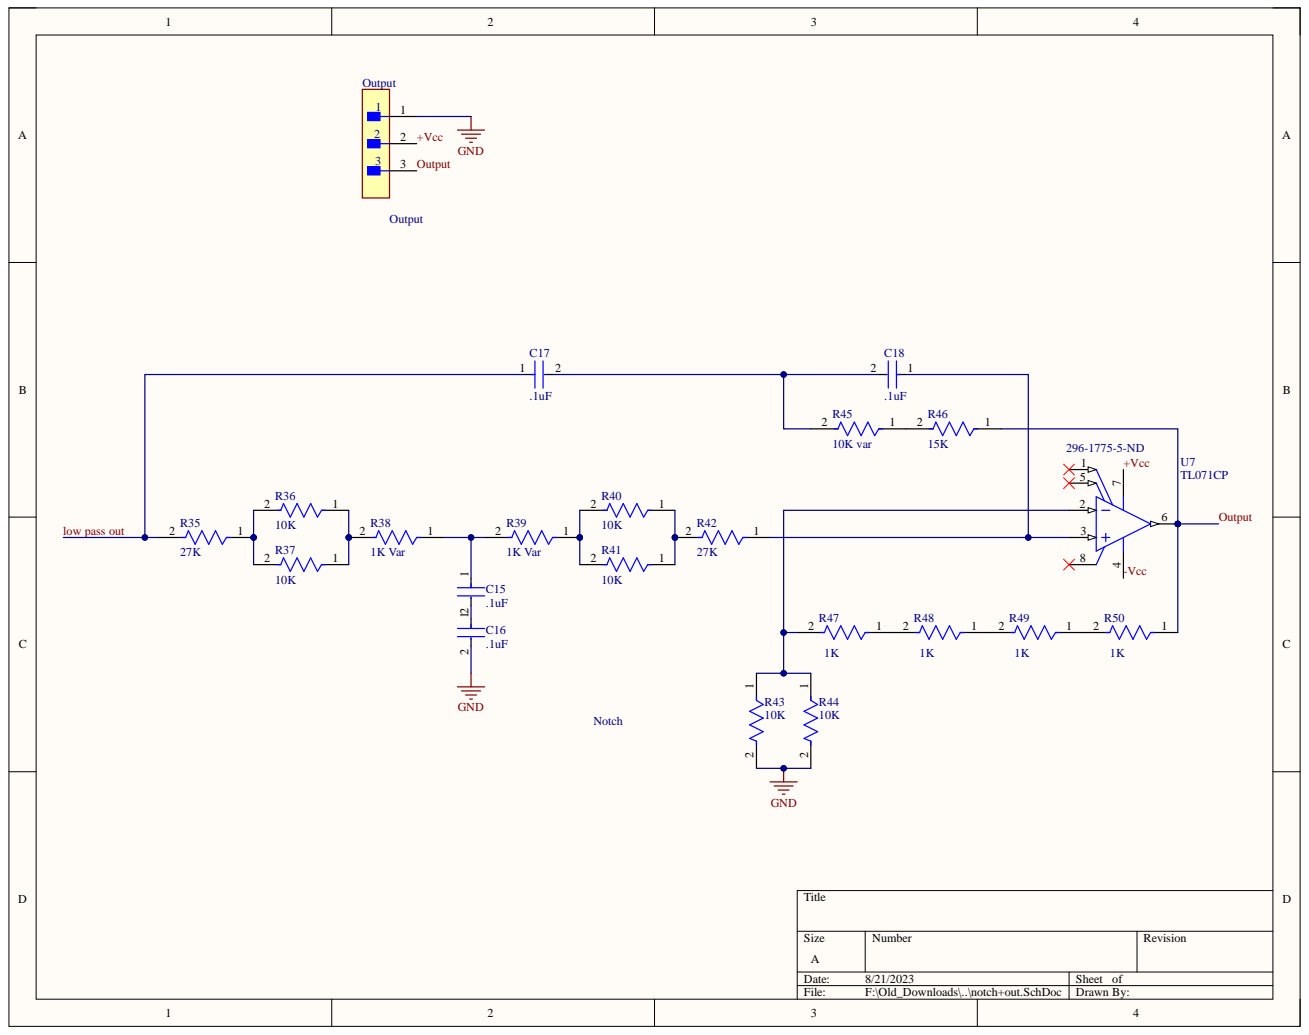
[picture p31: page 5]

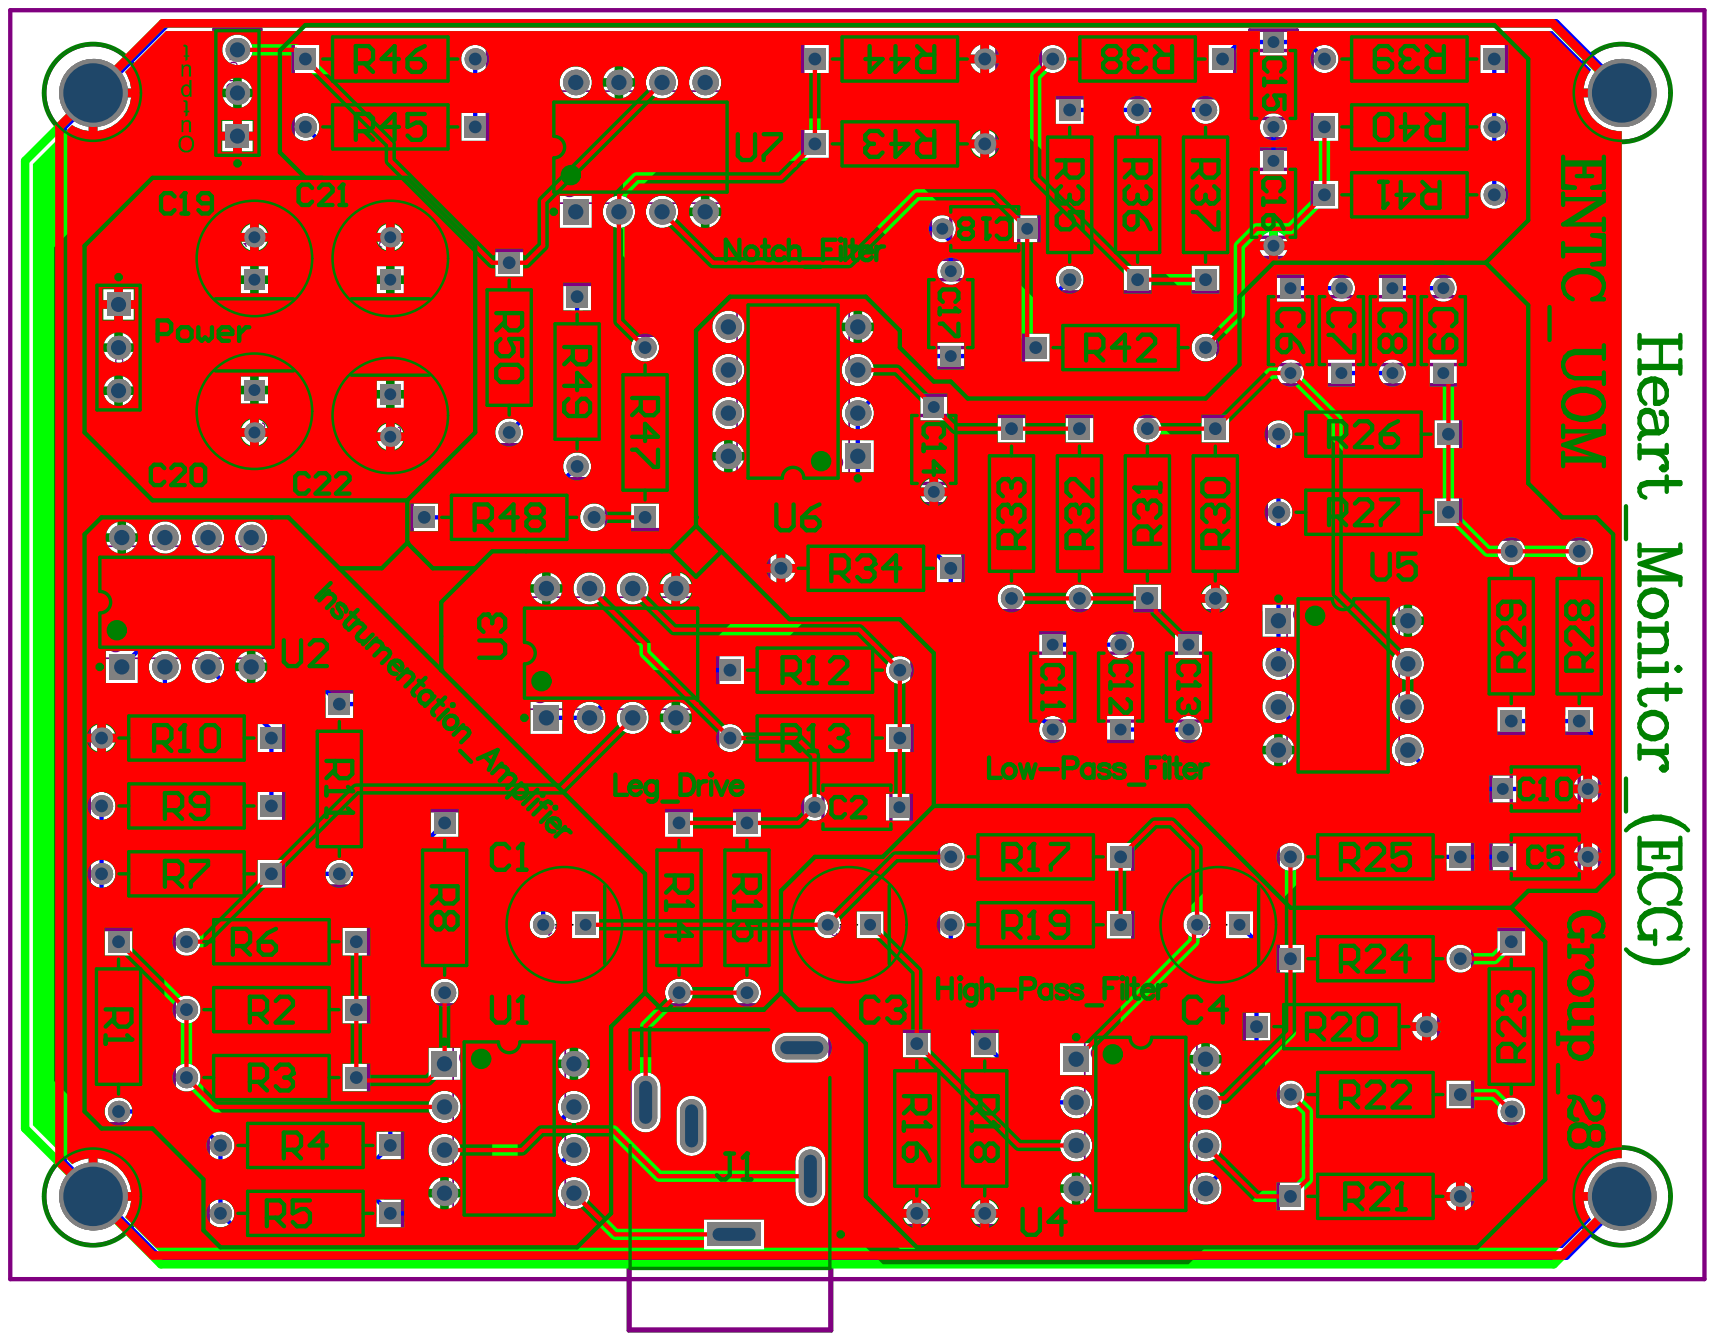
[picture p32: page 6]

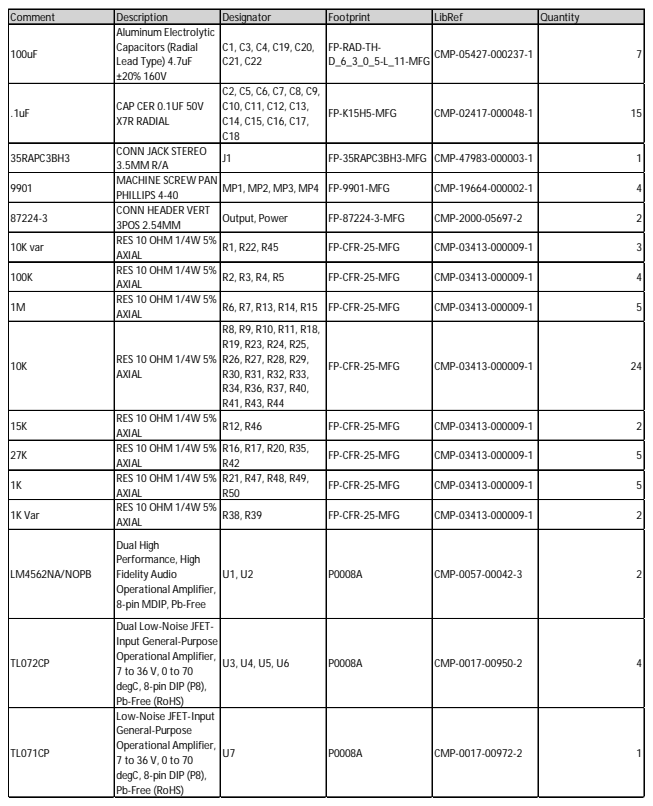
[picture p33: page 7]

Comment | Description | Designator | Footprint | LibRef | Quantity
100uF | Aluminum Electrolytic Capacitors (Radial Lead Type) 4.7uF ±20% 160V | C1, C3, C4, C19, C20, C21, C22 | FP-RAD-TH-D_6_3_0_5-L_11-MFG | CMP-05427-000237-1 | 7

.1uF | CAP CER 0.1UF 50V X7R RADIAL | C2, C5, C6, C7, C8, C9, C10, C11, C12, C13, C14, C15, C16, C17, C18 | FP-K15H5-MFG | CMP-02417-000048-1 | 15

35RAPC3BH3 | CONN JACK STEREO 3.5MM R/A | J1 | FP-35RAPC3BH3-MFG | CMP-47983-000003-1 | 1

9901 | MACHINE SCREW PAN PHILLIPS 4-40 | MP1, MP2, MP3, MP4 | FP-9901-MFG | CMP-19664-000002-1 | 4

87224-3 | CONN HEADER VERT 3POS 2.54MM | Output, Power | FP-87224-3-MFG | CMP-2000-05697-2 | 2

10K var | RES 10 OHM 1/4W 5% AXIAL | R1, R22, R45 | FP-CFR-25-MFG | CMP-03413-000009-1 | 3

100K | RES 10 OHM 1/4W 5% AXIAL | R2, R3, R4, R5 | FP-CFR-25-MFG | CMP-03413-000009-1 | 4

1M | RES 10 OHM 1/4W 5% AXIAL | R6, R7, R13, R14, R15 | FP-CFR-25-MFG | CMP-03413-000009-1 | 5

10K | RES 10 OHM 1/4W 5% AXIAL | R8, R9, R10, R11, R18, R19, R23, R24, R25, R26, R27, R28, R29, R30, R31, R32, R33, R34, R36, R37, R40, R41, R43, R44 | FP-CFR-25-MFG | CMP-03413-000009-1 | 24

15K | RES 10 OHM 1/4W 5% AXIAL | R12, R46 | FP-CFR-25-MFG | CMP-03413-000009-1 | 2

27K | RES 10 OHM 1/4W 5% AXIAL | R16, R17, R20, R35, R42 | FP-CFR-25-MFG | CMP-03413-000009-1 | 5

1K | RES 10 OHM 1/4W 5% AXIAL | R21, R47, R48, R49, R50 | FP-CFR-25-MFG | CMP-03413-000009-1 | 5

1K Var | RES 10 OHM 1/4W 5% AXIAL | R38, R39 | FP-CFR-25-MFG | CMP-03413-000009-1 | 2

LM4562NA/NOPB | Dual High Performance, High Fidelity Audio Operational Amplifier, 8-pin MDIP, Pb-Free | U1, U2 | P0008A | CMP-0057-00042-3 | 2

TL072CP | Dual Low-Noise JFET-Input General-Purpose Operational Amplifier, 7 to 36 V, 0 to 70 degC, 8-pin DIP (P8), Pb-Free (RoHS) | U3, U4, U5, U6 | P0008A | CMP-0017-00950-2 | 4

TL071CP | Low-Noise JFET-Input General-Purpose Operational Amplifier, 7 to 36 V, 0 to 70 degC, 8-pin DIP (P8), Pb-Free (RoHS) | U7 | P0008A | CMP-0017-00972-2 | 1

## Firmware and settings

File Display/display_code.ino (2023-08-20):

#include <Adafruit_GFX.h>    
#include <Adafruit_TFTLCD.h> 

#define LCD_CS A3 
#define LCD_CD A2 
#define LCD_WR A1 
#define LCD_RD A0
#define LCD_RESET A4

#define LTBLUE    0xB6DF
#define LTTEAL    0xBF5F
#define LTGREEN         0xBFF7
#define LTCYAN    0xC7FF
#define LTRED           0xFD34
#define LTMAGENTA       0xFD5F
#define LTYELLOW        0xFFF8
#define LTORANGE        0xFE73
#define LTPINK          0xFDDF
#define LTPURPLE  0xCCFF
#define LTGREY          0xE71C

#define BLUE            0x001F
#define TEAL    0x0438
#define GREEN           0x07E0
#define CYAN          0x07FF
#define RED           0xF800
#define MAGENTA       0xF81F
#define YELLOW        0xFFE0
#define ORANGE        0xFD20
#define PINK          0xF81F
#define PURPLE    0x801F
#define GREY        0xC618
#define WHITE         0xFFFF
#define BLACK         0x0000

#define DKBLUE        0x000D
#define DKTEAL    0x020C
#define DKGREEN       0x03E0
#define DKCYAN        0x03EF
#define DKRED         0x6000
#define DKMAGENTA       0x8008
#define DKYELLOW        0x8400
#define DKORANGE        0x8100
#define DKPINK          0x9009
#define DKPURPLE      0x4010
#define DKGREY        0x4A49

#define ADJ_PIN A5

boolean display1 = true;
boolean display2 = true;
boolean display3 = true;
boolean display4 = true;
boolean display5 = true;
boolean display6 = true;
boolean display7 = true;
boolean display8 = true;
boolean display9 = true;
boolean display10 = true;
boolean display11 = true;
boolean display12 = true;
boolean display13 = true;
boolean display14 = true;
boolean display15 = true;
boolean display16 = true;
boolean display17 = true;
boolean display18 = true;
boolean display19 = true;
boolean display20 = true;
boolean display21 = true;
boolean display22 = true;
boolean display23 = true;
boolean display24 = true;
boolean display25 = true;
boolean display26 = true;
boolean display27 = true;
boolean display28 = true;
boolean display29 = true;
boolean display30 = true;
boolean display31 = true;
boolean display32 = true;
boolean display33 = true;
boolean display34 = true;
boolean display35 = true;

double vo;
double ox , oy;

Adafruit_TFTLCD tft(LCD_CS, LCD_CD, LCD_WR, LCD_RD, LCD_RESET);

void Graph(Adafruit_TFTLCD &d, double x, double y, double gx, double gy, double w, double h, double xlo, double xhi, double xinc, double ylo, double yhi, double yinc, String title, String xlabel, String ylabel, unsigned int gcolor, unsigned int acolor, unsigned int pcolor, unsigned int tcolor, unsigned int bcolor, boolean &redraw) {

  double ydiv, xdiv;
  // initialize old x and old y in order to draw the first point of the graph
  // but save the transformed value
  // note my transform funcition is the same as the map function, except the map uses long and we need doubles
  //static double ox = (x - xlo) * ( w) / (xhi - xlo) + gx;
  //static double oy = (y - ylo) * (gy - h - gy) / (yhi - ylo) + gy;
  double i;
  double temp;
  int rot, newrot;

  if (redraw == true) {

    redraw = false;
    ox = (x - xlo) * ( w) / (xhi - xlo) + gx;
    oy = (y - ylo) * (gy - h - gy) / (yhi - ylo) + gy;
    // draw y scale
    for ( i = ylo; i <= yhi; i += yinc) {
      // compute the transform
      temp =  (i - ylo) * (gy - h - gy) / (yhi - ylo) + gy;

      if (i == 0) {
        d.drawLine(gx, temp, gx + w, temp, acolor);
      }
      else {
        d.drawLine(gx, temp, gx + w, temp, gcolor);
      }

      d.setTextSize(1);
      d.setTextColor(tcolor, bcolor);
      d.setCursor(gx - 40, temp);
      // precision is default Arduino--this could really use some format control
      d.println(i);
    }
    // draw x scale
    for (i = xlo; i <= xhi; i += xinc) {

      // compute the transform

      temp =  (i - xlo) * ( w) / (xhi - xlo) + gx;
      if (i == 0) {
        d.drawLine(temp, gy, temp, gy - h, acolor);
      }
      else {
        d.drawLine(temp, gy, temp, gy - h, gcolor);
      }

      d.setTextSize(1);
      d.setTextColor(tcolor, bcolor);
      d.setCursor(temp, gy + 10);
      // precision is default Arduino--this could really use some format control
      d.println(i);
    }

    //now draw the labels
    d.setTextSize(2);
    d.setTextColor(tcolor, bcolor);
    d.setCursor(gx , gy - h - 30);
    d.println(title);

    d.setTextSize(1);
    d.setTextColor(acolor, bcolor);
    d.setCursor(gx , gy + 20);
    d.println(xlabel);

    d.setTextSize(1);
    d.setTextColor(acolor, bcolor);
    d.setCursor(gx - 30, gy - h - 10);
    d.println(ylabel);

  }

  //graph drawn now plot the data
  // the entire plotting code are these few lines...
  // recall that ox and oy are initialized as static above
  x =  (x - xlo) * ( w) / (xhi - xlo) + gx;
  y =  (y - ylo) * (gy - h - gy) / (yhi - ylo) + gy;
  d.drawLine(ox, oy, x, y, pcolor);
  d.drawLine(ox, oy + 1, x, y + 1, pcolor);
  d.drawLine(ox, oy - 1, x, y - 1, pcolor);
  ox = x;
  oy = y;

}

/*
  End of graphing functioin
*/

void setup() {
  Serial.begin(115200);
  tft.begin(0x9341);
  tft.fillScreen(BLACK);
  tft.setRotation(1);
  pinMode(ADJ_PIN, INPUT);

  for (int x = 0; x < 60; x += 1) {
    vo = analogRead(ADJ_PIN) / 204.6;
    Graph(tft, x, vo, 50, 290, 390, 260, 0, 60, 10, 0, 5, 1, "ECG MONITOR", " Time [s]", "Heart rate", DKBLUE, RED, GREEN, WHITE, BLACK, display1);
    delay(100);                                
  }
  
  delay(1000);
  tft.fillScreen(BLACK);

  for (int x = 0; x < 60; x += 1) {
    vo = analogRead(ADJ_PIN) / 204.6;
    Graph(tft, x, vo, 50, 290, 390, 260, 0, 60, 10, 0, 5, 1, "ECG MONITOR", " Time [s]", "Heart rate", DKBLUE, RED, GREEN, WHITE, BLACK, display2);
    delay(100);
  }
  
  delay(1000);
  tft.fillScreen(BLACK);
  for (int x = 0; x < 60; x += 1) {
    vo = analogRead(ADJ_PIN) / 204.6;
    Graph(tft, x, vo, 50, 290, 390, 260, 0, 60, 10, 0, 5, 1, "ECG MONITOR", " Time [s]", "Heart rate", DKBLUE, RED, GREEN, WHITE, BLACK, display3);
    delay(100);
  }
  
  delay(1000);
  tft.fillScreen(BLACK);
  for (int x = 0; x < 60; x += 1) {
    vo = analogRead(ADJ_PIN) / 204.6;
    Graph(tft, x, vo, 50, 290, 390, 260, 0, 60, 10, 0, 5, 1, "ECG MONITOR", " Time [s]", "Heart rate", DKBLUE, RED, GREEN, WHITE, BLACK, display4);
    delay(100);
  }
  
  delay(1000);
  tft.fillScreen(BLACK);
  for (int x = 0; x < 60; x += 1) {
    vo = analogRead(ADJ_PIN) / 204.6;
    Graph(tft, x, vo, 50, 290, 390, 260, 0, 60, 10, 0, 5, 1, "ECG MONITOR", " Time [s]", "Heart rate", DKBLUE, RED, GREEN, WHITE, BLACK, display5);
    delay(100);
  }
  
  delay(1000);
  tft.fillScreen(BLACK);
  for (int x = 0; x < 60; x += 1) {
    vo = analogRead(ADJ_PIN) / 204.6;
    Graph(tft, x, vo, 50, 290, 390, 260, 0, 60, 10, 0, 5, 1, "ECG MONITOR", " Time [s]", "Heart rate", DKBLUE, RED, GREEN, WHITE, BLACK, display6);
    delay(100);
  }
  
  delay(1000);
  tft.fillScreen(BLACK);
  for (int x = 0; x < 60; x += 1) {
    vo = analogRead(ADJ_PIN) / 204.6;
    Graph(tft, x, vo, 50, 290, 390, 260, 0, 60, 10, 0, 5, 1, "ECG MONITOR", " Time [s]", "Heart rate", DKBLUE, RED, GREEN, WHITE, BLACK, display7);
    delay(100);
  }
  
  delay(1000);
  tft.fillScreen(BLACK);
  for (int x = 0; x < 60; x += 1) {
    vo = analogRead(ADJ_PIN) / 204.6;
    Graph(tft, x, vo, 50, 290, 390, 260, 0, 60, 10, 0, 5, 1, "ECG MONITOR", " Time [s]", "Heart rate", DKBLUE, RED, GREEN, WHITE, BLACK, display8);
    delay(100);
  }
  
  delay(1000);
  tft.fillScreen(BLACK);
  for (int x = 0; x < 60; x += 1) {
    vo = analogRead(ADJ_PIN) / 204.6;
    Graph(tft, x, vo, 50, 290, 390, 260, 0, 60, 10, 0, 5, 1, "ECG MONITOR", " Time [s]", "Heart rate", DKBLUE, RED, GREEN, WHITE, BLACK, display9);
    delay(100);
  }
  
  delay(1000);
  tft.fillScreen(BLACK);
  for (int x = 0; x < 60; x += 1) {
    vo = analogRead(ADJ_PIN) / 204.6;
    Graph(tft, x, vo, 50, 290, 390, 260, 0, 60, 10, 0, 5, 1, "ECG MONITOR", " Time [s]", "Heart rate", DKBLUE, RED, GREEN, WHITE, BLACK, display10);
    delay(100);
  }
  
  delay(1000);
  tft.fillScreen(BLACK);
  for (int x = 0; x < 60; x += 1) {
    vo = analogRead(ADJ_PIN) / 204.6;
    Graph(tft, x, vo, 50, 290, 390, 260, 0, 60, 10, 0, 5, 1, "ECG MONITOR", " Time [s]", "Heart rate", DKBLUE, RED, GREEN, WHITE, BLACK, display11);
    delay(100);
  }
  
  delay(1000);
  tft.fillScreen(BLACK);


for (int x = 0; x < 60; x += 1) {
    vo = analogRead(ADJ_PIN) / 204.6;
    Graph(tft, x, vo, 50, 290, 390, 260, 0, 60, 10, 0, 5, 1, "ECG MONITOR", " Time [s]", "Heart rate", DKBLUE, RED, GREEN, WHITE, BLACK, display12);
    delay(100);
  }
  
  delay(1000);
  tft.fillScreen(BLACK);

for (int x = 0; x < 60; x += 1) {
    vo = analogRead(ADJ_PIN) / 204.6;
    Graph(tft, x, vo, 50, 290, 390, 260, 0, 60, 10, 0, 5, 1, "ECG MONITOR", " Time [s]", "Heart rate", DKBLUE, RED, GREEN, WHITE, BLACK, display13);
    delay(100);
  }
  
  delay(1000);
  tft.fillScreen(BLACK);

for (int x = 0; x < 60; x += 1) {
    vo = analogRead(ADJ_PIN) / 204.6;
    Graph(tft, x, vo, 50, 290, 390, 260, 0, 60, 10, 0, 5, 1, "ECG MONITOR", " Time [s]", "Heart rate", DKBLUE, RED, GREEN, WHITE, BLACK, display14);
    delay(100);
  }
  
  delay(1000);
  tft.fillScreen(BLACK);

for (int x = 0; x < 60; x += 1) {
    vo = analogRead(ADJ_PIN) / 204.6;
    Graph(tft, x, vo, 50, 290, 390, 260, 0, 60, 10, 0, 5, 1, "ECG MONITOR", " Time [s]", "Heart rate", DKBLUE, RED, GREEN, WHITE, BLACK, display15);
    delay(100);
  }
  
  delay(1000);
  tft.fillScreen(BLACK);

for (int x = 0; x < 60; x += 1) {
    vo = analogRead(ADJ_PIN) / 204.6;
    Graph(tft, x, vo, 50, 290, 390, 260, 0, 60, 10, 0, 5, 1, "ECG MONITOR", " Time [s]", "Heart rate", DKBLUE, RED, GREEN, WHITE, BLACK, display16);
    delay(100);
  }
  
  delay(1000);
  tft.fillScreen(BLACK);

for (int x = 0; x < 60; x += 1) {
    vo = analogRead(ADJ_PIN) / 204.6;
    Graph(tft, x, vo, 50, 290, 390, 260, 0, 60, 10, 0, 5, 1, "ECG MONITOR", " Time [s]", "Heart rate", DKBLUE, RED, GREEN, WHITE, BLACK, display17);
    delay(100);
  }
  
  delay(1000);
  tft.fillScreen(BLACK);

for (int x = 0; x < 60; x += 1) {
    vo = analogRead(ADJ_PIN) / 204.6;
    Graph(tft, x, vo, 50, 290, 390, 260, 0, 60, 10, 0, 5, 1, "ECG MONITOR", " Time [s]", "Heart rate", DKBLUE, RED, GREEN, WHITE, BLACK, display18);
    delay(100);
  }
  
  delay(1000);
  tft.fillScreen(BLACK);

for (int x = 0; x < 60; x += 1) {
    vo = analogRead(ADJ_PIN) / 204.6;
    Graph(tft, x, vo, 50, 290, 390, 260, 0, 60, 10, 0, 5, 1, "ECG MONITOR", " Time [s]", "Heart rate", DKBLUE, RED, GREEN, WHITE, BLACK, display19);
    delay(100);
  }
  
  delay(1000);
  tft.fillScreen(BLACK);

for (int x = 0; x < 60; x += 1) {
    vo = analogRead(ADJ_PIN) / 204.6;
    Graph(tft, x, vo, 50, 290, 390, 260, 0, 60, 10, 0, 5, 1, "ECG MONITOR", " Time [s]", "Heart rate", DKBLUE, RED, GREEN, WHITE, BLACK, display20);
    delay(100);
  }
  
  delay(1000);
  tft.fillScreen(BLACK);

for (int x = 0; x < 60; x += 1) {
    vo = analogRead(ADJ_PIN) / 204.6;
    Graph(tft, x, vo, 50, 290, 390, 260, 0, 60, 10, 0, 5, 1, "ECG MONITOR", " Time [s]", "Heart rate", DKBLUE, RED, GREEN, WHITE, BLACK, display21);
    delay(100);
  }
  
  delay(1000);
  tft.fillScreen(BLACK);

for (int x = 0; x < 60; x += 1) {
    vo = analogRead(ADJ_PIN) / 204.6;
    Graph(tft, x, vo, 50, 290, 390, 260, 0, 60, 10, 0, 5, 1, "ECG MONITOR", " Time [s]", "Heart rate", DKBLUE, RED, GREEN, WHITE, BLACK, display22);
    delay(100);
  }
  
  delay(1000);
  tft.fillScreen(BLACK);

for (int x = 0; x < 60; x += 1) {
    vo = analogRead(ADJ_PIN) / 204.6;
    Graph(tft, x, vo, 50, 290, 390, 260, 0, 60, 10, 0, 5, 1, "ECG MONITOR", " Time [s]", "Heart rate", DKBLUE, RED, GREEN, WHITE, BLACK, display23);
    delay(100);
  }
  
  delay(1000);
  tft.fillScreen(BLACK);

for (int x = 0; x < 60; x += 1) {
    vo = analogRead(ADJ_PIN) / 204.6;
    Graph(tft, x, vo, 50, 290, 390, 260, 0, 60, 10, 0, 5, 1, "ECG MONITOR", " Time [s]", "Heart rate", DKBLUE, RED, GREEN, WHITE, BLACK, display24);
    delay(100);
  }
  
  delay(1000);
  tft.fillScreen(BLACK);

for (int x = 0; x < 60; x += 1) {
    vo = analogRead(ADJ_PIN) / 204.6;
    Graph(tft, x, vo, 50, 290, 390, 260, 0, 60, 10, 0, 5, 1, "ECG MONITOR", " Time [s]", "Heart rate", DKBLUE, RED, GREEN, WHITE, BLACK, display25);
    delay(100);
  }
  
  delay(1000);
  tft.fillScreen(BLACK);

for (int x = 0; x < 60; x += 1) {
    vo = analogRead(ADJ_PIN) / 204.6;
    Graph(tft, x, vo, 50, 290, 390, 260, 0, 60, 10, 0, 5, 1, "ECG MONITOR", " Time [s]", "Heart rate", DKBLUE, RED, GREEN, WHITE, BLACK, display26);
    delay(100);
  }
  
  delay(1000);
  tft.fillScreen(BLACK);

  for (int x = 0; x < 60; x += 1) {
    vo = analogRead(ADJ_PIN) / 204.6;
    Graph(tft, x, vo, 50, 290, 390, 260, 0, 60, 10, 0, 5, 1, "ECG MONITOR", " Time [s]", "Heart rate", DKBLUE, RED, GREEN, WHITE, BLACK, display27);
    delay(100);
  }
  
  delay(1000);
  tft.fillScreen(BLACK);

  for (int x = 0; x < 60; x += 1) {
    vo = analogRead(ADJ_PIN) / 204.6;
    Graph(tft, x, vo, 50, 290, 390, 260, 0, 60, 10, 0, 5, 1, "ECG MONITOR", " Time [s]", "Heart rate", DKBLUE, RED, GREEN, WHITE, BLACK, display28);
    delay(100);
  }
  
  delay(1000);
  tft.fillScreen(BLACK);

  for (int x = 0; x < 60; x += 1) {
    vo = analogRead(ADJ_PIN) / 204.6;
    Graph(tft, x, vo, 50, 290, 390, 260, 0, 60, 10, 0, 5, 1, "ECG MONITOR", " Time [s]", "Heart rate", DKBLUE, RED, GREEN, WHITE, BLACK, display29);
    delay(100);
  }
  
  delay(1000);
  tft.fillScreen(BLACK);

  for (int x = 0; x < 60; x += 1) {
    vo = analogRead(ADJ_PIN) / 204.6;
    Graph(tft, x, vo, 50, 290, 390, 260, 0, 60, 10, 0, 5, 1, "ECG MONITOR", " Time [s]", "Heart rate", DKBLUE, RED, GREEN, WHITE, BLACK, display30);
    delay(100);
  }
  
  delay(1000);
  tft.fillScreen(BLACK);
  for (int x = 0; x < 60; x += 1) {
    vo = analogRead(ADJ_PIN) / 204.6;
    Graph(tft, x, vo, 50, 290, 390, 260, 0, 60, 10, 0, 5, 1, "ECG MONITOR", " Time [s]", "Heart rate", DKBLUE, RED, GREEN, WHITE, BLACK, display31);
    delay(100);
  }
  
  delay(1000);
  tft.fillScreen(BLACK);

  for (int x = 0; x < 60; x += 1) {
    vo = analogRead(ADJ_PIN) / 204.6;
    Graph(tft, x, vo, 50, 290, 390, 260, 0, 60, 10, 0, 5, 1, "ECG MONITOR", " Time [s]", "Heart rate", DKBLUE, RED, GREEN, WHITE, BLACK, display32);
    delay(100);
  }
  
  delay(1000);
  tft.fillScreen(BLACK);

  for (int x = 0; x < 60; x += 1) {
    vo = analogRead(ADJ_PIN) / 204.6;
    Graph(tft, x, vo, 50, 290, 390, 260, 0, 60, 10, 0, 5, 1, "ECG MONITOR", " Time [s]", "Heart rate", DKBLUE, RED, GREEN, WHITE, BLACK, display33);
    delay(100);
  }
  
  delay(1000);
  tft.fillScreen(BLACK);

  for (int x = 0; x < 60; x += 1) {
    vo = analogRead(ADJ_PIN) / 204.6;
    Graph(tft, x, vo, 50, 290, 390, 260, 0, 60, 10, 0, 5, 1, "ECG MONITOR", " Time [s]", "Heart rate", DKBLUE, RED, GREEN, WHITE, BLACK, display34);
    delay(100);
  }
  
  delay(1000);
  tft.fillScreen(BLACK);

  for (int x = 0; x < 60; x += 1) {
    vo = analogRead(ADJ_PIN) / 204.6;
    Graph(tft, x, vo, 50, 290, 390, 260, 0, 60, 10, 0, 5, 1, "ECG MONITOR", " Time [s]", "Heart rate", DKBLUE, RED, GREEN, WHITE, BLACK, display35);
    delay(100);
  }
  
  delay(1000);
  tft.fillScreen(BLACK);
}

void loop(void) { 
}
